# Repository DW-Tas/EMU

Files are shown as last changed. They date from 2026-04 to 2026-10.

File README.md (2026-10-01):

[][cc-by-nc-sa]

# EMU – Expandable Multi-material Unit
### A new take on a MMU by <a href="https://github.com/DW-Tas">DW-Tas</a> and <a href="https://github.com/igiannakas">igiannakas</a><br/>
<a href="https://ko-fi.com/O5O5OCC0K"> Ko-Fi</a>

**Introducing the EMU, the Expandable Multi-material Unit from down under.** The EMU is a modular, flexible, upgradable, reliable and service-friendly MMU designed around the proven filamentalist V3 platform.

The EMU supports any number of lanes and base configurations; whether it is a **single lane setup** to assist filament loading, a **dual lane configuration** for endless spool, or a **multi-lane, multi base unit setup** for multi-material printing. It is also **expandable**, with no re-printing of parts required when upgrading from a 2 lane to a multiple lane setup.

> [!TIP]
> ### EMU Kits
> Officially certified kits are now available. Further information on sourcing links, kits and kit classification can be found [in the dedicated sourcing page](https://github.com/DW-Tas/EMU/blob/main/docs/sourcing.md).
> ### Crossbow Filament Cutter And A4T Toolhead
> Make the EMU part of a complete system with the [Crossbow Filament Cutter](https://github.com/DW-Tas/Crossbow-Filament-Cutter) and the [A4T Toolhead](https://github.com/Armchair-Heavy-Industries/A4T).

<p align="center">
  
</p>

## Discord - primary support communities
Join our active communities on Discord using the links below. We are active on both the Armchair Engineering, Happy Hare and Voron discord servers.<br/>
Join me on Discord (https://discord.gg/hG2NRazKG3)   
<br>
**HappyHare Discord:** https://discord.gg/Yt8Fe7FkNc

## Table of Contents
- [Design Objectives](#design-objectives)
- [Documentation](/docs)
  - [Sourcing](/docs/sourcing.md)
  - [Printed parts configurator](https://emu.dwtas.net)
  - [Printing, Assembly and Wiring](/docs/assembly_wiring)
  - [Board Setup and Flashing](/docs/software_setup/01-board-setup.md)
  - [Software Setup](/docs/software_setup/02-software-setup.md)
  - [Calibration and Startup](/docs/software_setup/03-calibration-and-startup.md)
  - [Expanding the Unit](/docs/software_setup/04-expanding-the-unit.md)
  - [Slicer setup and optimisation for multi color prints](/docs/software_setup/05-slicer-setup.md)
  - [Updating CAN Boards with UKAM](/docs/software_setup/06-updating-can-boards.md)
  - [Manual Sensorless Toolhead Calibration for Happy Hare](/docs/software_setup/07-manual-toolhead-calibration.md)
  - [Manual Toolhead Calibration with Two Sensors for Happy Hare](/docs/software_setup/08-manual_toolhead_calibration_two_sensors.md)
  - [Legacy Happy Hare v3 guides (archive)](/docs/software_setup/legacy_hhv3)
- [Render Gallery](#render-gallery)
- [Prints Gallery](#prints-gallery)
- [License](#this-work-is-licensed-under-a)

## EMU Highlights
- **Modular & Expandable** design, able to add lanes anytime and in any configuration. No reprints when upgrading from a 2 lane setup.
- **One screw or tool-free** access and servicing, even mid-print.
- **Sealed dry boxes** able to maintain humidity in the 15% range (with silica gel) or 5–8% range (with molecular sieves) for weeks.  
- **Humidity sensors** per lane for filament environmental monitoring.
- **Reliable endless spool** with no chance of the rewound filament interfering with neighbouring rolls.
- **Off-the-shelf electronics** (EBB42 with EBB36 also fully compatible). Custom designed Solo Lane Boards (SLB) available as an option, to ease wiring.
- **Per-lane controls** - eject button + LEDs.

<p align="center">
  
  
</p>

## Design Objectives

### Modularity & Upgradeability  
Each lane is fully self-contained, so you can choose **exactly how many lanes you need and group them as you like**. You can also **mix and match** lanes across multiple base units, or use a stand-alone single lane for extruder loading and print assistance. 

Expanding later is also straightforward. Just print lane expanders for the base and add another dry box assembly. There is no need to reprint or replace existing parts when upgrading from a 2 lane base. 

### Ease of Servicing 
All electrical and mechanical components are either **one screw or completely tool-free and immediately accessible**, making live troubleshooting possible even during a print. 

Access to the electronics is easy - just lift the dry box off its base for full access. The stepper tensioning screw is accessible without any disassembly allowing on the fly tuning of filament grip. Finally, removing the filamentalist, stepper and stepper assembly is possible via one screw.

### Sealed Dry Boxes  
Each spool sits in its own purpose built, **fully sealed dry box with an integrated desiccant holder**. The boxes use foam cord in areas of potential air ingress to create a tight seal, with the clear 1.5mm PETG/PC panel also offering visibility inside the dry box.

The dry boxes can maintain humidity in the 15% range (with silica gel) or 5–8% range (with molecular sieves) for weeks. Finally, as each dry box is self contained, opening one to reload filament, doesn’t disturb its neighbours, extending the effective desiccant life.

<p align="center">
  
</p>

### Integrated Humidity Sensors 
Each lane monitors its own environment, letting you know when it’s **time to refresh the desiccant**. The humidity sensors are integrated into Mainsail (and optionally in Home Assistant for historical data tracking via the mainsail HA integration).

### Endless Spool Reliability
Dual pre-stepper sensors ensure **consistent run-out detection** and reliable re-wind, as the filament is always gripped by the stepper hobbed gear assembly. 

In addition, the isolated boxes ensure that any left over, rewound, filament cannot interfere with neighbouring lanes, **preventing a jam**.

### Built on the Filamentalist
The lane assembly is based on the proven **[filamentalist V3 design with 688 bearings](https://github.com/Enraged-Rabbit-Community/ERCF_v2/tree/master/Recommended_Options/Filamentalist_Rewinder/Filamentalist_FV3_Rewinder)** with wide spool size compatibility. Built on the 74mm filamentalist setup, the unit fits even the slightly wider KVP filament spools.

<p align="center">
  
  
</p>

### Integrated Filament Driving Stepper 
Each lane has its own driving stepper inside the dry box, resulting in a compact, **fully self-contained mechanical design**. In case of mechanical issue, you can swap out filamentalist assemblies with 3 screws, unplugging 2 JST plugs and unplugging the bowden tube. 

In addition, you can **swap out complete dry boxes** by unplugging two JST plugs and the bowden tube. This is helpful if you want to maintain a particularly moisture sensitive filament undisturbed when swapping it out from the EMU.

### Simple Electronics
The recommended BOM uses the custom designed [Solo Lane Boards](https://www.aliexpress.com/item/1005012025112049.html) which simplify wiring greatly. Also the **readily available EBB42 & EBB36 boards** are fully compatible. MMB v2 boards (or any other controller board with adequate number of endstops) can also be reused, though without humidity sensing due to I²C limitations and a slightly more intricate wiring. 

In addition, **each lane has its own ventilation fan**, ensuring the stepper drivers do not overheat, even when the unit is placed on top of a hot printer.

### Easy mounting
The EMU base assembly can be securely **mounted on extrusions** or using **rubber feet** directly on the printer or besides it. In either case the **electronics remain accessible** without needing to remove the unit from its mounts.

### Per-lane Controls  
Each lane includes its own eject button, status LED, and a filament colour LED that illuminates the dry box. 

## Render Gallery
<p align="center">
  
  
</p>
<p align="center">
  
  
</p>
<br/>

## Prints Gallery
<p align="center">
  1 (4)
  1 (5)
  1 (2)
  1 (3)
</p>

## Mods to main
The following mods from the community have been adopted into the main EMU release
 - Rim roller with square nuts: [martijnvanduijneveldt](https://github.com/martijnvanduijneveldt)
 - EMU Wiring Hatch Board: [kashine6](https://github.com/kashine6)

## This work is licensed under a
[Creative Commons Attribution-NonCommercial-ShareAlike 4.0 International License][cc-by-nc-sa].

[][cc-by-nc-sa]

[cc-by-nc-sa]: http://creativecommons.org/licenses/by-nc-sa/4.0/
[cc-by-nc-sa-image]: https://licensebuttons.net/l/by-nc-sa/4.0/88x31.png
[cc-by-nc-sa-shield]: https://img.shields.io/badge/License-CC%20BY--NC--SA%204.0-lightgrey.svg

## License clarification regarding non-commercial use:
The non-commercial aspect of this license is for cases where EMU is the product, not the use of EMU to create products.<br/>
I.e. If you wish to sell EMU as a product, you would need to seek a commercial license before doing so. </br>
It is NOT intended to prevent the use of EMU with a printer that you use to provide commercial services. If you want to run EMU in your print farm, go right ahead.

---

[Documentation →](/docs)

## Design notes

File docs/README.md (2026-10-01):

[][cc-by-nc-sa]

# EMU – Expandable Multi-material Unit Documentation
### A new take on a MMU by <a href="https://github.com/DW-Tas">DW-Tas</a> and <a href="https://github.com/igiannakas">igiannakas</a><br/>
<a href="https://ko-fi.com/O5O5OCC0K"> Ko-Fi</a>

<p align="center">
  
</p>

## Step 1: [Sourcing](/docs/sourcing.md)
The dedicated [sourcing page](/docs/sourcing.md) contains kit, certification and BOM information.

## Step 2: [Printing, Assembly and Wiring](/docs/assembly_wiring)
This page explains the EMU parts printing, assembly and wiring. It contains the [printed parts configurator, which allows you to select the desired number of lanes and build options](https://emu.dwtas.net), detailed print settings for all of the EMU parts, including tips on how to achieve the optimal print results. It also includes the [assembly manuals](/Manuals), (legacy) videos and covers multi-lane and single-lane wiring for EMU SLB, EBB42 & 36 boards.

- [Printed parts configurator](https://emu.dwtas.net)
- [Print Settings](/docs/assembly_wiring/#print-settings)
  - [Filamentalist components and Lane stepper components](/docs/assembly_wiring/#filamentalist-components-and-lane-stepper-components)
  - [Dry Box components](/docs/assembly_wiring/#dry-box-components)
  - [Base unit components](/docs/assembly_wiring/#base-unit-components)
- [Assembly Manuals](/docs/assembly_wiring/#assembly-manuals)
- [Assembly Videos](/docs/assembly_wiring/#assembly-videos)
  - [Part 1: Filamentalist and Stepper Assembly Guide](/docs/assembly_wiring/#part-1-filamentalist-and-stepper-assembly-guide)
  - [Part 2: Drybox Assembly Guide](/docs/assembly_wiring/#part-2-drybox-assembly-guide)
  - [Part 3: Base Assembly Guide](/docs/assembly_wiring/#part-3-base-assembly-guide)
  - [Part 4: Electronics Assembly Guide](/docs/assembly_wiring/#part-4-electronics-assembly-guide)
- [Wiring Instructions and Diagrams](/docs/assembly_wiring/#wiring-instructions-and-diagrams)

## Step 3: [EMU Board Setup](/docs/software_setup/01-board-setup.md)
This page explains in detail how to setup your EMU boards with CANBus, how to flash Katapult and klipper as well as the procedure to update the klipper firmware.

- [Setting up CAN Bus](/docs/software_setup/01-board-setup.md#setting-up-can-bus)
- [Setting up and flashing the EBB boards](/docs/software_setup/01-board-setup.md#setting-up-and-flashing-the-ebb-boards)
- [Updating the boards with the latest klipper version](/docs/software_setup/01-board-setup.md#updating-the-boards-with-the-latest-klipper-version)

## Step 4: [Software Setup](/docs/software_setup/02-software-setup.md)
The EMU needs MMU control software running alongside Klipper. Both of the options below support the EMU natively. The EMU was developed on Happy Hare and it's the software we have the most experience with. However, AFC is equally an option if you prefer it or already use it, with its setup covered in the AFC documentation.

**Happy Hare v4:** The step by step install and set up process is maintained in the Happy Hare documentation. EMU-specific notes are on the [companion page in this repo](/docs/software_setup/02-software-setup.md#happy-hare-v4).

- [Getting Started with EMU (Happy Hare v4 documentation)](https://moggieuk.github.io/Happy-Hare-Doc/GettingStarted-EMU/)
- [EMU notes for the v4 installer](/docs/software_setup/02-software-setup.md#emu-notes-for-the-v4-installer)
- [Legacy Happy Hare v3 setup guide](/docs/software_setup/legacy_hhv3/02-happy-hare-setup.md) (existing v3 installs only)

**AFC (AFC-Klipper-Add-On):** In the AFC installer (`install-afc.sh`), choose **EMU** as the unit type, then set your lane count and board type (SLB or EBB). Follow the [AFC documentation](https://www.afcproject.dev/) for the full process.

- [AFC installation guide](https://www.afcproject.dev/installation/getting-started.html)
- [AFC Initial Startup & Commissioning guide](https://www.afcproject.dev/initial-startup/01-overview.html) (select the EMU tab)

> [!NOTE]
> Step 5 (Calibration and Startup), the machine G-code in Step 6 (Slicer Setup) and [Expanding the unit](/docs/software_setup/04-expanding-the-unit.md) are written for Happy Hare. If you use AFC, follow the AFC [calibration](https://www.afcproject.dev/installation/calibration.html) and [slicer setup](https://www.afcproject.dev/installation/slicer-setup.html) guides instead.

## Step 5: [Calibration and Startup](/docs/software_setup/03-calibration-and-startup.md)
This page explains the initial start up checks required to ensure successful first operation, and the step by step process to calibrate the unit.

- [First start up](/docs/software_setup/03-calibration-and-startup.md#first-start-up)
- [Calibrating the unit](/docs/software_setup/03-calibration-and-startup.md#calibrating-the-unit)
- [Manual unit calibration (optional)](/docs/software_setup/03-calibration-and-startup.md#manual-unit-calibration-optional---if-not-satisfied-with-automated-calibrations)

## Step 6: [Slicer Setup and Optimisation for Multi Color Prints](/docs/software_setup/05-slicer-setup.md)
Describes the mandatory Orca slicer setup required for single extruder multi-material printing, including print profile settings to achieve optimal quality results.

- [Orca slicer mandatory setup](/docs/software_setup/05-slicer-setup.md#orca-slicer-mandatory-setup)
- [Orca slicer profile tuning for multi-color printing](/docs/software_setup/05-slicer-setup.md#orca-slicer-profile-tuning-for-multi-color-printing)

## Step 7: [Updating CAN Boards with UKAM](/docs/software_setup/06-updating-can-boards.md)
Automate Klipper firmware updates across all your EMU CAN bus boards using UKAM (Update Klipper And MCUs), instead of manually flashing each board.

## Next steps
Once you have completed the steps above you should have a fully functioning EMU unit! Optionally you can also set up:
1. Klipper screen integration: https://moggieuk.github.io/Happy-Hare-Doc/KlipperScreen/
2. Mainsail / Fluidd MMU panel: https://moggieuk.github.io/Happy-Hare-Doc/Mainsail-Fluidd-Integration/
3. Spoolman: https://moggieuk.github.io/Happy-Hare-Doc/Feature-Spoolman/

In addition, to add further lanes, follow the instructions here: [Expanding the unit](/docs/software_setup/04-expanding-the-unit.md)

> [!NOTE]
> **Running Happy Hare v3?** The previous v3 setup, calibration and expansion guides are kept in the [legacy Happy Hare v3 archive](/docs/software_setup/legacy_hhv3).

## Seeking help

Join our active communities on Discord using the links below. We are active on both the Armchair Engineering and Happy Hare discord servers below.

Join me on Discord (https://discord.gg/hG2NRazKG3)   
<br>
**HappyHare Discord:** https://discord.gg/Yt8Fe7FkNc

#### This work is licensed under a
[Creative Commons Attribution-NonCommercial-ShareAlike 4.0 International License][cc-by-nc-sa].

[][cc-by-nc-sa]

[cc-by-nc-sa]: http://creativecommons.org/licenses/by-nc-sa/4.0/
[cc-by-nc-sa-image]: https://licensebuttons.net/l/by-nc-sa/4.0/88x31.png
[cc-by-nc-sa-shield]: https://img.shields.io/badge/License-CC%20BY--NC--SA%204.0-lightgrey.svg

### License clarification regarding non-commercial use:
The non-commercial aspect of this license is for cases where EMU is the product, not the use of EMU to create products.<br/>
I.e. If you wish to sell EMU as a product, you would need to seek a commercial license before doing so. </br>
It is NOT intended to prevent the use of EMU with a printer that you use to provide commercial services. If you want to run EMU in your print farm, go right ahead.

---

← [Main README](/) | [Step 1: Sourcing →](/docs/sourcing.md)

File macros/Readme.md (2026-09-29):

# EMU – Custom macros and Klipper modules

This folder contains three sets of files:
1. `emu_macros.cfg`
2. Klipper module patches for the AHT and BME sensors
3. UKAM menuconfig templates to automate Klipper firmware updates

## Using the emu_macros.cfg file
Place the `emu_macros.cfg` file in your printer configuration folder. Update your `printer.cfg` to use it by adding the following line after all the MMU macro inclusions:

`[include emu_macros.cfg]`

Configure the macros [as per the instructions in the legacy Happy Hare v3 setup guide](https://github.com/DW-Tas/EMU/blob/main/docs/software_setup/legacy_hhv3/02-happy-hare-setup.md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).

Both HW and SW I2C bus definitions are included. If planning to use the upcomming EMU NFC reader functionality, HW I2C is required. Please note in some setups HW I2C may generate NACK errors. If you do encounter that, check wiring crimping and at worst revert to SW I2C (but without NFC functionality).

## Using the custom Klipper modules
The stock Klipper setup has two shortcomings when using a BME or AHT sensor:
1. The BME sensor polls every 0.8 seconds, placing needless load on the MCU.
2. The AHT sensor does not report humidity to 1 decimal place; instead, it rounds to a whole number.

The two included files are drop-in replacements for Klipper modules and address these two shortcomings. Specifically for the BME sensor, the default polling behaviour is set to 5 seconds and is also configurable from your `emu_macros.cfg` file as shown below:

```
[temperature_sensor Lane_0]
sensor_type: BME280
bme280_report_time: 120 # new parameter controlling polling frequency
i2c_address: 118
i2c_mcu: mmu0
i2c_software_scl_pin: mmu0:PB3
i2c_software_sda_pin: mmu0:PB4
```
To use these files, download them from the EMU repo and upload them to your SBC in the following location, overwriting the default files: `~/klipper/klippy/extras`

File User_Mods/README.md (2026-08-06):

# EMU User Mods

Community-contributed modifications and additions for the EMU (Expandable Multi-material Unit). Browse the table below to find mods that extend or customise your EMU setup.

## Usermods

| Mod | Author | Description | Preview |
|-----|---|---|---|
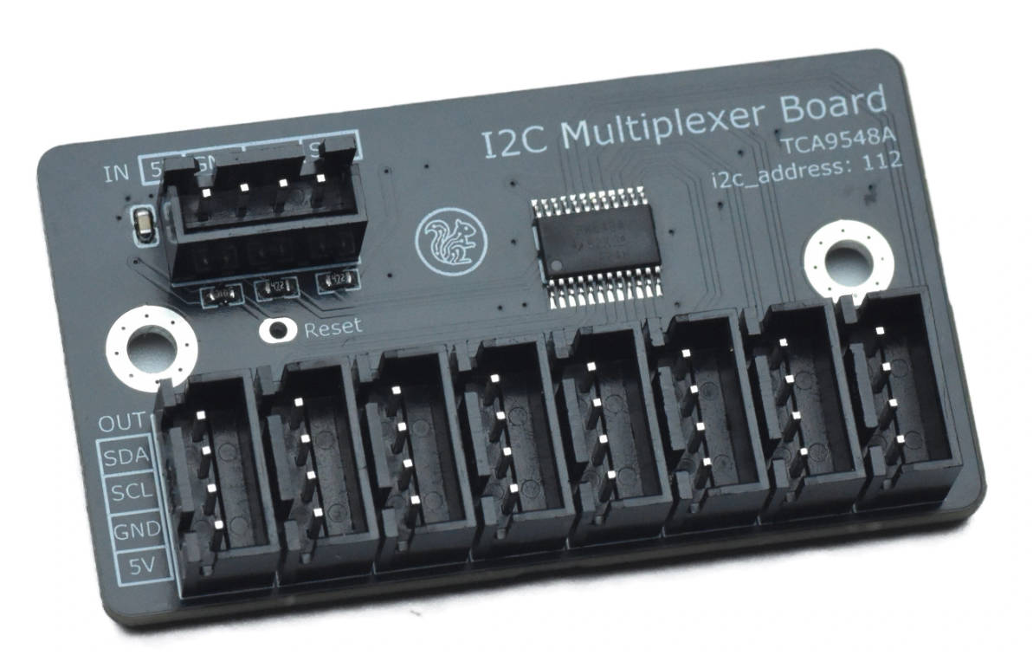
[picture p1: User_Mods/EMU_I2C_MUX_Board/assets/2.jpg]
| [EMU_I2C_MUX_Board](EMU_I2C_MUX_Board) | [kashine6](https://github.com/kashine6) | Custom TCA9548A I2C Mux Board for MMB Users |  |
| [DFRobot SHT31 Holder](DFRobot_SHT31_Holder) | [reapola](https://github.com/reapola) | High-accuracy temperature & humidity sensor holder, replacing the standard BME280 |  |
| [EMU Cable Entry – Crimpable JST](EMU%20Cable%20Entry_Crimpable_JST) | [Dragi2k](https://github.com/Dragi2k) | Cable entry module with crimpable JST socket options for 3- and 4-pin configurations |  |
| [EMUSync Mount](EMUSync_Mount) | [cwiegert](https://github.com/cwiegert) | Mount to stabilise the PSF body in the bowden path with perpendicular or parallel mounting options |  |
| [EMU Cable Entry Blank Plate](EMU_Cable_Entry) | [bartlammers](https://github.com/bartlammers) | Blank cable entry plate for sides without cables, compatible with multimaterial printing |  |
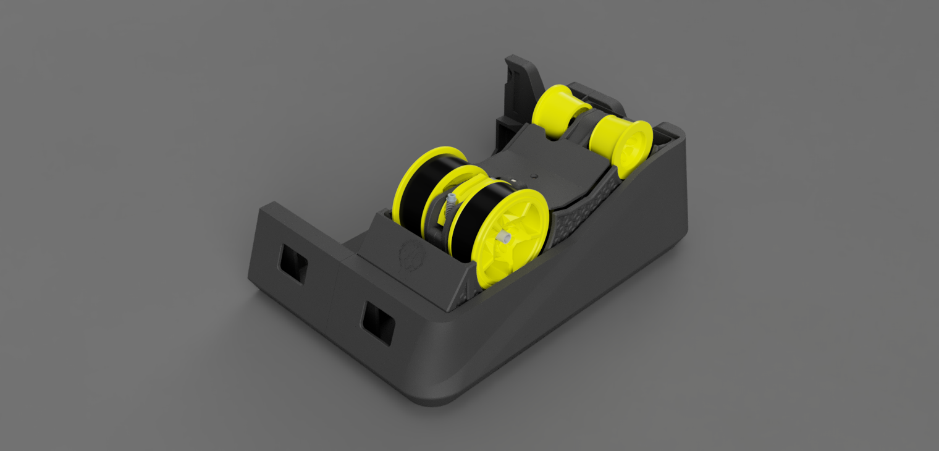
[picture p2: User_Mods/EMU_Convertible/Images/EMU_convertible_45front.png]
| [EMU Convertible](EMU_Convertible) | [Dragi2k](https://github.com/Dragi2k) | Use wider spools (84 mm) in outer bays or centre with the adjacent bay populated |  |
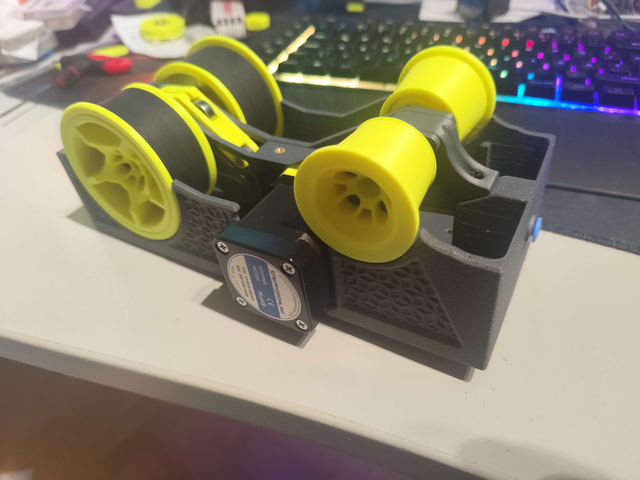
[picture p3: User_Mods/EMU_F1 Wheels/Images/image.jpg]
| [EMU F1 Wheels](EMU_F1%20Wheels) | [Dragi2k](https://github.com/Dragi2k) | Stylish wheel remix compatible with EMU Lite and EMU Convertible for wider wheel accommodation |  |
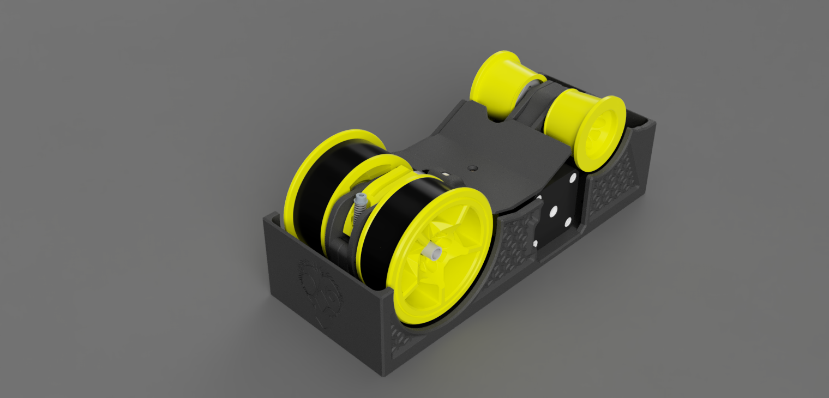
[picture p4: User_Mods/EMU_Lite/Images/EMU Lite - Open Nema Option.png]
| [EMU Lite](EMU_Lite) | [Dragi2k](https://github.com/Dragi2k) | Simplified EMU without lid or base, fully compatible with EMU Filamentalist and hatch board |  |
| [EMU Roller Rubber Installer](EMU_Roller_Rubber_Installer) | [wil1972](https://github.com/wil1972) | Tools for cutting and installing rubber bike tyre on EMU rollers using zip ties |  |
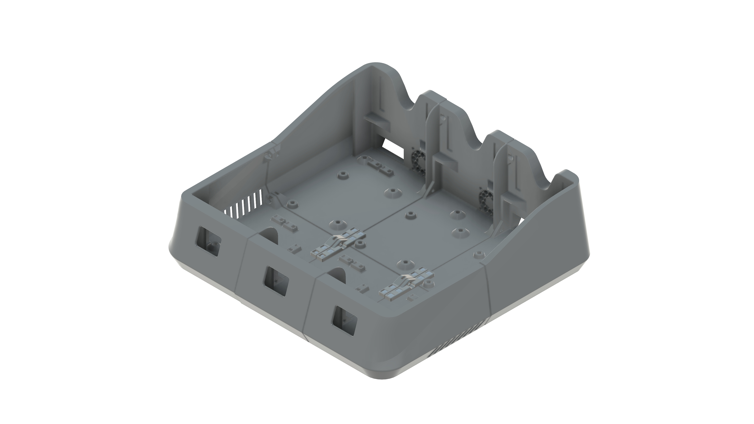
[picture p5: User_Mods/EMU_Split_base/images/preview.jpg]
| [EMU Split base](EMU_Split_base) | [martijnvanduijneveldt](https://github.com/martijnvanduijneveldt) | Split base version for smaller printers |  |
| [Micron EMU Hat](MicronEMU) | [burkfers](https://github.com/burkfers) | Base unit mod fitting three EMU boxes onto a Micron with a stealth aesthetic |  |
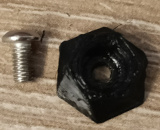
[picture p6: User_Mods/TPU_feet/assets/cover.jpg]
| [printable TPU feet](TPU_feet) | [burkfers](https://github.com/burkfers) | Small M3-mounted printable feet for the bottom of the base |  |
| [Rim Roller with Square Nuts](Rim_Roller_with_square_nuts) | [martijnvanduijneveldt](https://github.com/martijnvanduijneveldt) | Rim roller remix using square nuts instead of screwing directly into plastic |  |
| [Trianglelab BLV kit mods](Trianglelab_BLV%20kit%20mods) | [DW-Tas](https://github.com/DW-Tas) | PTC212-413 connector holder as a Wago 221 alternative for the Trianglelab BLV kit | — |

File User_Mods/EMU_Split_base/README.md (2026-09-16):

# EMU Split base

| Top view | Bottom view |
|---|---|
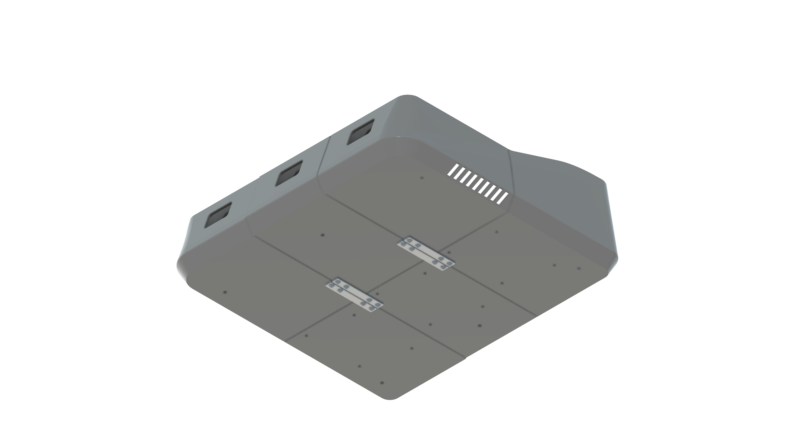
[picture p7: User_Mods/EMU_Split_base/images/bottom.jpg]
| Preview |  |

A remix splitting the different base parts so they can be printed on smaller printers.

The position of the side connector matches of original position, so mixing split bases with full bases it possible.

> This mod adds some protrusion (~4mm) on the bottom, so feet are required (even if they are already part of the standard bom).

## Extra required bom

The M3x8 SHCS screw + square nut to interconnect the lanes is already in the base bom so it's not needed as 'extra' for each lane.

### Left and right lane
These are the extra requirements for a single side, multiply by 2 if printing both sides

|Amount | Part | Placement |
|---|---|---|
| 2x | M3x8 SHCS | On the outer side of the box | 
| 4x | M3x8 BHCS | On the bottom of the inner side connector |
| 4x | Square nuts | On the top of the inner side connector |

### Expander lane(s)

|Amount | Part | Placement |
|---|---|---|
| 8x | M3x8 BHCS | On the bottom of the side connectors |
| 8x | Square nuts | On the top of the side connectors |

## Credits
- Original mod by [martijnvanduijneveldt](https://github.com/martijnvanduijneveldt)
- Printed & tested by [DeWarePeb](https://github.com/DeWarePeb)

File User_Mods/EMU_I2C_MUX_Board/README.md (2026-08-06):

# EMU I2C MUX Board

This user mod is a small PCB for wiring a TCA9548A I2C multiplexer into an
EMU setup more cleanly.

## Why

Some users may want to repurpose spare MMU controller boards, such as the MMB
or AFC-Lite, to build an EMU. In these configurations, convenient I2C connection 
points can run short when multiple I2C devices are connected. A TCA9548A multiplexer 
allows several downstreamI2C devices to share a single upstream I2C bus while keeping 
the devices isolated on separate mux channels.

This board was made to make that wiring easier and cleaner.

**Note:**

> Compared with the common off-the-shelf TCA9548A breakout board, this PCB does
> not add any new electrical or software functionality. Its purpose is only to
> simplify and organize the wiring for an EMU installation.

<p align="center">
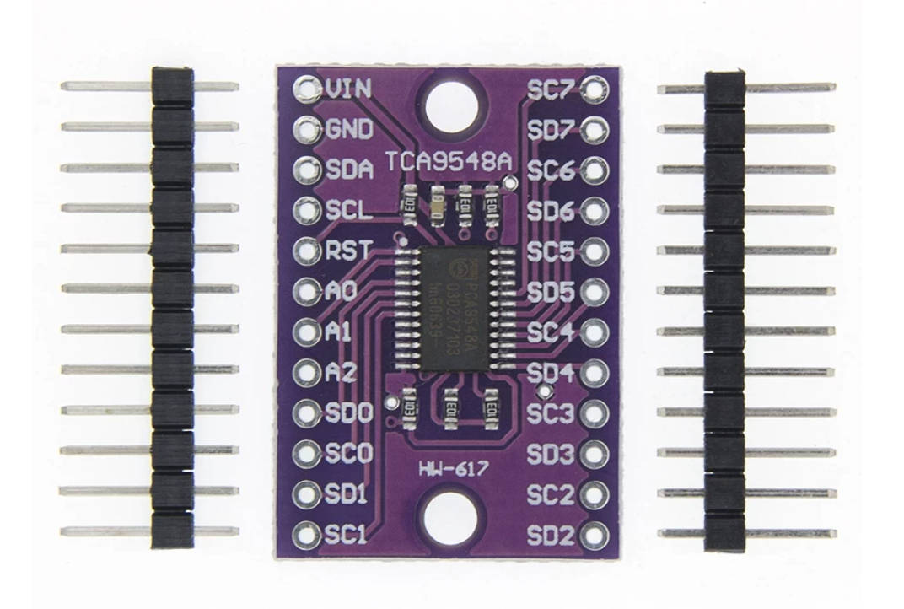
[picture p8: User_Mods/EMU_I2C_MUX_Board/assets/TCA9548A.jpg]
TCA9548A HW-617 breakout board
  
</p>

## Hardware

**Gerber** files for the PCB are included in this project, allowing you to order the board from 
your preferred PCB manufacturer.

Alternatively, you can purchase a PCB from AliExpress. Ordering it together with other EMU 
parts can help reduce shipping costs.

- https://www.aliexpress.com/item/1005011529532141.html

<p align="center">
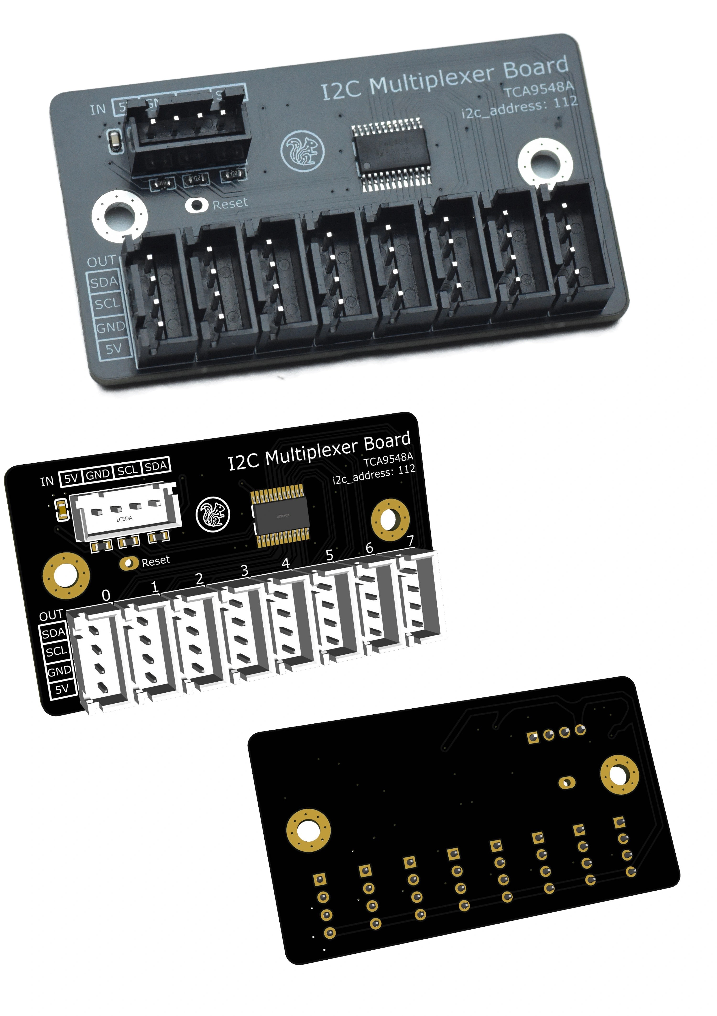
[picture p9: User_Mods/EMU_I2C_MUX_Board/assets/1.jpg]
EMU I2C MUX Board
  
</p>

## Mount
The PCB mount designed for EMU Lane Base is also available in this repository.

## Software

The matching Klipper software add-on is maintained separately:

<https://github.com/jacksky6/TCA9548A-klipper-addon>

That software project provides the actual TCA9548A mux support for Klipper,
including serialized channel selection and sensor adapters for devices behind
the mux. This PCB is only a wiring convenience board. It does not replace the
software add-on.

## License

This user mod is licensed under the Creative Commons
Attribution-NonCommercial-ShareAlike 4.0 International license.

See: <https://creativecommons.org/licenses/by-nc-sa/4.0/>

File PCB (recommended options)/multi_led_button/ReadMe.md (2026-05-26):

## EMU LED PCB

The **EMU LED PCB** is a dedicated PCB designed for the EMU to enable dynamic lighting effects on the eject button assembly. It also simplifies wiring and reduces the need for soldering.

LED PCB

## BOM variations vs. baseline EMU BOM
Do not purchase the below from the base BOM:
1. 1 less neopixel
2. 1 less D2F-L switch
3. 4 less 6x3mm magnets

Add the below to the base BOM, depending on your LED PCB source:
1. 1x JST-XH 5 pin PCB header

## Manual
Assembly and wiring instructions are outlined [in the manual](/Manuals/EMU_LED_Button_PCB.pdf).

## Sourcing
The LED button PCBs can be sourced from the below location:
1. [Aliexpress](https://www.aliexpress.com/item/1005011529532141.html) in sets of 5

Alternatively use the supplied gerber, BOM and pick and place files to order from your favourite PCB manufacturer.

## Software setup

Update your **LED definitions** in the mmu_hardware.cfg as below. **Key change is chain count is equal to 5 instead of 2.**
```
[neopixel mmu0_leds] # one block per lane (Lane 0)
pin: mmu0:MMU_NEOPIXEL
chain_count: 5			# four for the eject button and one for the box
color_order: GRBW		

[neopixel mmu1_leds] # one block per lane (Lane 1)
pin: mmu1:MMU_NEOPIXEL
chain_count: 5			# four for the eject button and one for the box
color_order: GRBW	

[....]

[neopixel mmuN_leds] # one block per lane (Lane 1)
pin: mmuN:MMU_NEOPIXEL
chain_count: 5			# four for the eject button and one for the box
color_order: GRBW
```
Update your **LED allocation** to exit and entry LEDs in the mmu_hardware.cfg as below. **Key change is that leds 1 through to 4 are exit LEDs and LED 5 is the entry LED.**
```
[mmu_leds unit0]
exit_leds:
  neopixel:mmu0_leds (1,2,3,4) # add/remove lines to match number of lanes. LED 1-4 is for the button
  neopixel:mmu1_leds (1,2,3,4)
  [...]
  neopixel:mmuN_leds (1,2,3,4)
entry_leds:
  neopixel:mmu0_leds (5) # add/remove lines to match number of lanes. LED 5 is for the box
  neopixel:mmu1_leds (5)
  [...]
  neopixel:mmuN_leds (5)
frame_rate: 24
```
Update the **mmu eject button hardware configuration** in the **mmu_eject_buttons_hw.cfg file**<br/><br/>
The below example setup is for an 8 lane unit. To set up a lower lane count, delete the corresponding `[gcode_button mmu_eject_button_N]` sections. If you have more than 8 lanes, add more blocks following the pattern below. 

Please note the `!` which is different to the software setup that uses D2F switches!

```
[gcode_button mmu_eject_button_0]
pin: ^!mmu0:EJECT_BUTTON
press_gcode: _MMU_EJECT_BUTTON GATE=0

[gcode_button mmu_eject_button_1]
pin: ^!mmu1:EJECT_BUTTON
press_gcode: _MMU_EJECT_BUTTON GATE=1

[gcode_button mmu_eject_button_2]
pin: ^!mmu2:EJECT_BUTTON
press_gcode: _MMU_EJECT_BUTTON GATE=2

[gcode_button mmu_eject_button_3]
pin: ^!mmu3:EJECT_BUTTON
press_gcode: _MMU_EJECT_BUTTON GATE=3

[gcode_button mmu_eject_button_4]
pin: ^!mmu4:EJECT_BUTTON
press_gcode: _MMU_EJECT_BUTTON GATE=4

[gcode_button mmu_eject_button_5]
pin: ^!mmu5:EJECT_BUTTON
press_gcode: _MMU_EJECT_BUTTON GATE=5

[gcode_button mmu_eject_button_6]
pin: ^!mmu6:EJECT_BUTTON
press_gcode: _MMU_EJECT_BUTTON GATE=6

[gcode_button mmu_eject_button_7]
pin: ^!mmu7:EJECT_BUTTON
press_gcode: _MMU_EJECT_BUTTON GATE=7
```

## Wiring variations
The DOut pin (LED out) should connect to a 600mm AWG26-28 wire going to the LED IN pin of the lane dry box. That way the third wago can be omitted.

## Lighting effects
The multiple LEDs incorporated in the eject button allow you to create loading/unloading animations like the below. Also the integrated SMD switch provides a more tactile feel vs. the D2F switch and magnet assembly. 

The lighting effects are enabled automatically by happy hare.

https://github.com/user-attachments/assets/2f268710-e0a5-41e1-b007-02235ff379cc

## This work is licensed under a
[Creative Commons Attribution-NonCommercial-ShareAlike 4.0 International License][cc-by-nc-sa].

[][cc-by-nc-sa]

[cc-by-nc-sa]: http://creativecommons.org/licenses/by-nc-sa/4.0/
[cc-by-nc-sa-image]: https://licensebuttons.net/l/by-nc-sa/4.0/88x31.png
[cc-by-nc-sa-shield]: https://img.shields.io/badge/License-CC%20BY--NC--SA%204.0-lightgrey.svg

## License clarification regarding non-commercial use:
The non-commercial aspect of this license is for cases where EMU is the product, not the use of EMU to create products.<br/>
I.e. If you wish to sell EMU as a product, you would need to seek a commercial license before doing so. </br>
It is NOT intended to prevent the use of EMU with a printer that you use to provide commercial services. If you want to run EMU in your print farm, go right ahead.

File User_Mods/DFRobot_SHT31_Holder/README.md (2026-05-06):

# DFRobot SHT31 Temperature & Humidity Sensor Holder

Hot & Sweaty

## Overview
High(er) accuracy temperature & humidity sensor for use in the boxes instead of a BME280.

- Pros
    - ±2%RH at 0%RH to 100%RH (at 25°C）humidity accuracy Vs. ±3%RH 20%RH to 80%RH
    - -40°C to 125°C temperature detection range Vs. -40°C to 85°C range (although if its that hot, you've got bigger problems!)
    - Legit Fermion sensor Vs. potential BME280 clones

- Cons
    - Bigger footprint
    - More expensive (~£7 Vs. £4 per sensor)

## BOM
- DFRobot part no: SEN0331

## Where to get them?

Stick to suppliers with a known supply chain.

#### Worldwide
- [Mouser](https://www.mouser.co.uk/c/?q=SEN0331)
- [Digikey](https://www.digikey.co.uk/en/products/detail/dfrobot/SEN0331/12324931)

#### UK
- [ThePiHut](https://thepihut.com/products/fermion-sht31-digital-temperature-humidity-sensor?variant=42046092607683)
- [Farnell](https://uk.farnell.com/dfrobot/sen0331/temp-humidity-sensor-breakout/dp/4308263)

## Print settings
Standard EMU settings (999 walls) with shrinkage factor for your chosen filament.

Hot & Sweaty

## Code

By default the SHT3X klipper module expects the sensor on 68 (0x44), however the DFRobot sensors can be found at 69 (0x45) unless ADR is connected to connected to GND.  Report time is set to poll every 120secs to reduce load on the mcus.

#### Example config for Lane_0 found in emu_macros.cfg

    [temperature_sensor Lane_0]
    sensor_type: SHT3X
    i2c_address: 69
    i2c_mcu: mmu0
    i2c_software_scl_pin: mmu0:PB3
    i2c_software_sda_pin: mmu0:PB4
    sht3x_report_time: 120

#### How it should look when working (4 lane example)

Working example

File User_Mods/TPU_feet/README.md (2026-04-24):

# Printable feet

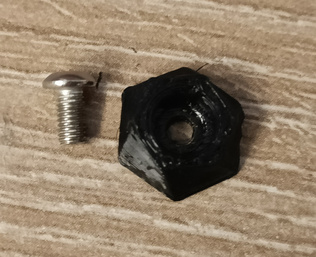
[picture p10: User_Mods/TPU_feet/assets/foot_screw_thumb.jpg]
a photograph of the foot in TPU next to an M3x6 BHCS on a wooden desk


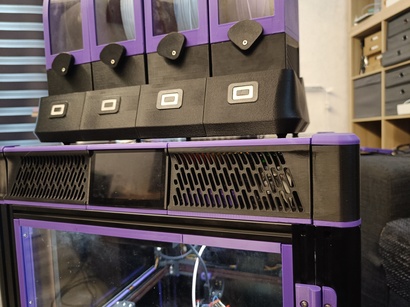
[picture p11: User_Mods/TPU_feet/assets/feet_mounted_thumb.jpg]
a photograph of a 4 lane EMU on top of a Doomcube, angled to show the gap and the feet


This small print adds reasonably low profile feet to the EMU. They can be printed in a flexible material to absorb some vibrations (especially when placed on top of the printer) and provide grip.

They have been tested in 95A TPU, printed with one wall, three tops and bottoms, and 10% gyroid infill.

Mount with an M3x6 BHCS each. Do not overtorque flexibles!

## Acknowledgements

Thanks to hartk for the inspiration by way of his Micron hexagonal feet.

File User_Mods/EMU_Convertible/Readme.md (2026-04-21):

# EMU Convertible

This mod allows the use of wider spools. In the outer bays of the base or in the center with an adjacent bay populated, 84 mm spools can be used. Even wider spools can be used in the center without side bays.
<br><br>
It is fully compatible, so only the EMU filamentalist needs to be replaced to eliminate the need for calibration.

| Front 45° | Closed Front | Opened Front |
|---|---|---|
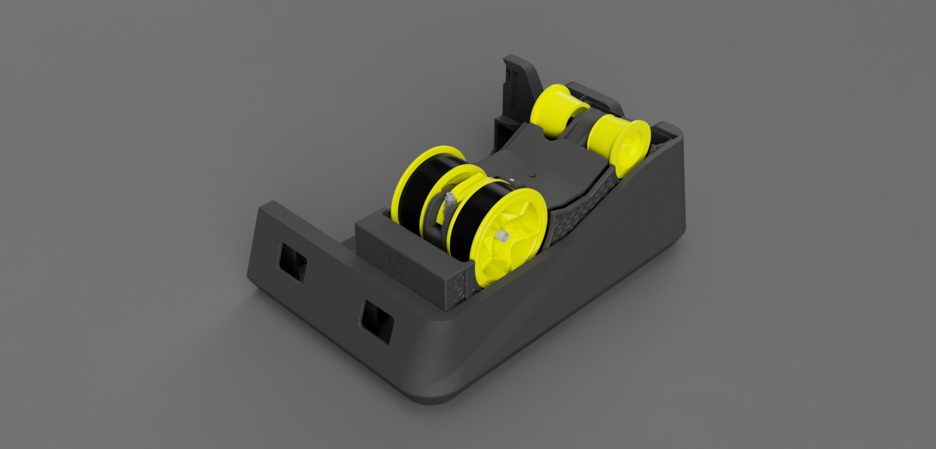
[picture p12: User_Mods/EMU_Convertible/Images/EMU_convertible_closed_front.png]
EMU Convertible closed front
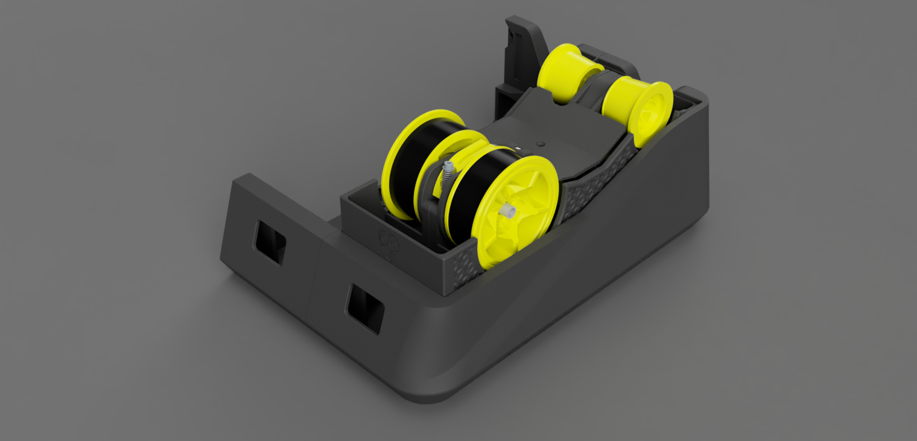
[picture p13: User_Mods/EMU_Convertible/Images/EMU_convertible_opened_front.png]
EMU Convertible opened front
| EMU Convertible 45 front |  |  |

by Dragi2k

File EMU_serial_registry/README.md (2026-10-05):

# EMU – Expandable Multi-material Unit - Official Serial Registry

EMU Serial Print by igiannakas

**Serial #0000:** dw.tas</br>
**Serial #0001:** igiannakas</br>
**Serial #0002:** Martijn</br>
**Serial #0003:** burkfers</br>
**Serial #0004:** WilLawUK</br>
**Serial #0005:** jacksky6</br>
**Serial #0006:** Heiliger-Gral</br>
**Serial #0007:** drachenkaetzchen</br>
**Serial #0008:** fronti</br>
**Serial #0009:** pajtaz</br>
**Serial #0010:** WoodWorker</br>
**Serial #0011:** Dragi2k</br>
**Serial #0012:** TheMeanCanEHdian</br>
**Serial #0013:** Bender</br>
**Serial #0014:** Pie36</br>
**Serial #0015:** ammaze</br>
**Serial #0016:** Doak</br>
**Serial #0017:** apoth82</br>
**Serial #0018:** .cicatrix</br>
**Serial #0019:** zoro__17</br>
**Serial #0020:** jimmyjon711</br>
**Serial #0021:** etherwalker</br>
**Serial #0022:** _yomgui_</br>
**Serial #0023:** sauyri</br>
**Serial #0024:** reapola</br>
**Serial #0025:** realadamator</br>
**Serial #0026:** ningpj</br>
**Serial #0027:** supercrossed</br>
**Serial #0028:** moadmoosa</br>
**Serial #0029:** niju5975</br>
**Serial #0030:** jb3duk</br>
**Serial #0031:** badman996</br>
**Serial #0032:** der_pw</br>
**Serial #0033:** hamido.</br>
**Serial #0034:** yssaril</br>
**Serial #0035:** _zimbo_</br>
**Serial #0036:** madscientist_304</br>
**Serial #0037:** mrga73</br>
**Serial #0038:** searsay3208</br>
**Serial #0039:** 8992</br>
**Serial #0040:** mrzottel79</br>
**Serial #0041:** bitmirth30</br>
**Serial #0042:** mahe_fi</br>
**Serial #0043:** etmolf</br>
**Serial #0044:** youngsterjon</br>
**Serial #0045:** margaale</br>
**Serial #0046:** bne6708</br>
**Serial #0047:** hcwarrior13</br>
</br>

### How to register:
Submit your build at [dwtas.net/EMUSerial](https://dwtas.net/EMUSerial). Sign in with Discord, upload a photo of your completed EMU Maker chip and unit, and a maintainer will review your submission.

Print [at least a two color version of the EMU Maker chip](https://github.com/DW-Tas/EMU/tree/main/EMU_serial_registry/serial_print_file). If your EMU lane can reach 4+ colors, try to use them all!

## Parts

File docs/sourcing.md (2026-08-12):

# EMU – Expandable Multi-material Unit Sourcing Options

## Sourcing Options
As EMU is using off the shelf hardware, you have 
two options to source the required components to build your unit: self sourcing and kits.

### EMU Kits
We require any officially authorised kits to **undergo a certification process**. During this process we test:
1. Completeness of the BOM
2. Fit of the mechanical parts
3. Level of effort required to complete the build
4. Convenience features for the user
5. Overall kit refinement

The kits are then classified into tiers, **Platinum**, **Gold**, **Silver**, **Bronze** as per the table below. 

This reflects the level of maturity of the kits and the overall user experience you should expect when ordering one.

It also allows us to offer feedback to the vendors to ensure the kits can result in a reliable unit and that any trade-offs are known up front to avoid buyer disappointment. 

### Certified Vendors List
<table style="width: 100%;">
  <tr>
    <th style="width: 10%;">Vendor</th>
    <th style="width: 30%;">Purchase Link</th>
    <th style="width: 30%;">Classification Tier</th>
    <th style="width: 30%;">Kit Summary</th>
  </tr>
  <tr>
    <td><strong>Vano3dla Maker Store</strong></td>
    <td><a href="https://www.aliexpress.com/item/1005012001238187.html">2 lane and 5 lane kit</a></td>
    <td>
      Platinum
    </td>
    <td>
      Platinum tier kit with all optional PCB options and exclusive PCB options included. High quality components, with exceptional fit and finish. Active support by the vendor in the Discord communities. <br><br> Initial batch of kits had the DIn - DOut silk screen on the Neopixel LEDs swapped around. 
    </td>
  </tr>
  <tr>
  <td><strong>DREMC (Vano3dla reseller)</strong></td>
  <td><a href="https://store.dremc.com.au/products/emu-the-expandable-multi-material-unit-hardware-kit">2 lane and 5 lane kit</a><br>Local Australian Stockist</td>
  <td>
    Platinum
  </td>
  <td>
    Platinum tier kit with all optional PCB options and exclusive PCB options included. High quality components, with exceptional fit and finish. Active support by the vendor in the Discord communities. <br><br> Initial batch of kits had the DIn - DOut silk screen on the Neopixel LEDs swapped around. 
  </td>
  </tr>
  <tr>
    <td><strong>onetwo3D</strong></td>
    <td><a href="https://www.onetwo3d.co.uk/product/emu-expandable-multi-material-unit-kit/">EMU base kit + lane kit(s)</a><br>Local UK Stockist</td>
    <td>
      Platinum
    </td>
    <td>
      <b>UK Based retailer, fast shipping. Modular purchase model:</b> buy one Base Kit per EMU system, then add one Lane Kit per lane required. Also excellent for existing kit expansion. <br><br>Kit includes EMU custom PCBs (hatch board and LED PCB), parts for stock EMUSync with option to add PSF, solo lane controller boards and IO Board separately. All optional boards (<a href="https://www.onetwo3d.co.uk/product/emu-solo-lane-board-slb/">Solo lane board</a>, <a href="https://www.onetwo3d.co.uk/product/psf-proportional-sync-feedback-sensor-for-mmu/">PSF</a>, <a href="https://www.onetwo3d.co.uk/product/emu-i-o-board/">EMU IO board</a>) stocked by OneTwo3D.<br/><br/>Kit includes pre-terminated wire looms, cut and crimped to size. Wiring for both SLB, EBB36/42 Gen 1, Gen 2, PSF and stock EMU Sync included. <br><br>Active support by the vendor in the Discord communities<br><br>Printed parts not included
    </td>
  </tr>
    <tr>
    <td><strong>Triangle Lab /</strong><br><strong>BLV</strong></td>
    <td><a href="https://aliexpress.com/item/1005012037255888.html">5 lane kit (trianglelab)</a>
    <br><br>
    <a href="https://aliexpress.com/item/1005012052899600.html">5 lane kit (BLV)</a><br><br>
      <a href="https://trianglelab.net/products/emu-5-lane-kit">5 lane kit (TL direct)</a>
    </td>
    <td>
      Silver
    </td>
    <td>
    Good quality core components kit requiring some additional wiring and assembly effort. Kit specifics:
    <ol>
      <li>⚠️ PRE-ASSEMBLED JST PLUGS: Take care to verify red and black wire locations. Initial shipments have these two wires swapped.</li>
      <li>Front switch PCB LED out wire is 300mm instead of 600mm. If using the Solo Lane Board, this is correct. If using an EBB, the user will need one additional WAGO, replacement of the 300mm LED out wire with a 600mm wire, or to solder the 300mm LED out wire to the 300mm LED in wire of the Hatch PCB.</li>
      <li>PCBs require soldering of the JST headers. All required JST headers and wires to assemble the kit are included.</li>
      <li>Wires are pre-crimped and assembled on the Box/front LED PCB connector side. The board side is uncrimped, but JST and Dupont crimps and plugs are provided. (See warning in point 1)</li>
      <li>WAGO alternatives are used. An alternative holder is required to be printed; the file is included in the usermod directory.</li>
      <li>Clear panel is 1.2mm thick. It is easier to assemble into place, with no expected impact on air-tightness.</li>
      <li>Sampled kit panel was 344mm instead of 343mm in length. Ensure the lid is correctly shrinkage compensated.</li>
      <li>Initial kits contain a Trianglelab-specific stepper. It provides higher torque at low speeds versus the BOM stepper, for example during printing, although maximum speed is limited to approximately 375mm/s. The stepper is planned to be swapped with the OMC BOM stepper in the future.</li>
      <li>One-way bearing and shaft, although hollow, are BOM-equivalent and showed correct, smooth motion.</li>
      <li>Stamped discs are included instead of demagnetised magnets for the Filamentalist sensors. These are functionally and dimensionally equivalent.</li>
      <li>Sampled kit did not include the M3x12 BHCS, or SHCS alternative. Subsequent kits should have this corrected.</li>
    </ol>
    </td>
  </tr>
<table>

### Controller Boards
In addition to the kit of your choice, one controller board per lane is required.
- **Recommended:** Solo lane board (SLB) [Ali Express](https://www.aliexpress.com/item/1005012025112049.html) [OneTwo3D](https://www.onetwo3d.co.uk/product/emu-solo-lane-board-slb/)- significantly simplifies wiring of the individual units.
- **Alternatively:** An EBB 42 or EBB 36 is also functional on the unit, with a bit more effort on crimping the necessary connectors.

### Certification Tiers
<table style="width: 100%;">
  <tr>
    <th style="width: 12%;">Tier</th>
    <th style="width: 18%;">User Experience</th>
    <th>Description</th>
  </tr>
  <tr>
    <td><strong>Platinum</strong></td>
    <td>The highest quality kit for the best user experience</td>
    <td>
      • It includes all core and optional BOM components at their highest possible quality with no tradeoffs.<br>
      • The mechanical components have excellent fit with limited/no re-work required by the end user.<br>
      • The kit includes all optional extras (PCB hatch boards, Eject button multi-LED board). Kit includes the Proportional Sync Feedback sensor and any additional PCBs that the kit vendor deems appropriate to ease assembly (eg. cable entry board)<br>
      • Wiring is pre-cut and crimped according to the universal wiring kit specifications / wiring guide. This means no crimping when using JST capable boards and limited crimping required when using EBB42/36 Gen 1 boards.<br>
      • All additional crimps and connectors as specified in the BOM are included in the kit enabling the widest array of boards to be used.
    </td>
  </tr>
  <tr>
    <td><strong>Gold</strong></td>
    <td>A high quality kit offering a good user experience</td>
    <td>
      • It includes all core and optional BOM components, with only minor tradeoffs in part selection where these do not materially affect functionality, reliability, or the overall build experience.<br>
      • The mechanical components have good fit, with potentially only minor re-work or adjustment required by the end user during assembly (eg. heat treating the one way bearing)<br>
      • The kit includes all optional extras (PCB hatch boards, Eject button multi-LED board). The Proportional Sync Feedback sensor may be omitted in lieu off a dual switch EMU Sync.<br>
      • Wiring is pre-cut and crimped according to the universal wiring kit specifications / wiring guide. This means no crimping when using JST capable boards and limited crimping required when using EBB42/36 Gen 1 boards.<br>
      • All additional crimps and connectors as specified in the BOM are included in the kit enabling the widest array of boards to be used..
    </td>
  </tr>
  <tr>
    <td><strong>Silver</strong></td>
    <td>A functional kit with a good but less refined user experience. Suitable for experienced builders who are comfortable with some additional build effort.</td>
    <td>
      • It includes the core BOM items required to complete a working build, but some optional extras or higher quality component choices may be omitted (eg. use of hollow steel tubes vs. solid, use of alternative stepper motors).<br>
      • The mechanical components are generally usable and will result in a functional build, but moderate re-work or adjustment may be required during assembly (eg. heat treating the one way bearing, de-magnetising the magnets manually).<br>
      • The kit may not include all optional extras, ie some of the PCBs may be omitted or come partly assembled, requiring the user to solder the JST connectors.<br>
      • Wiring may be only partially prepared, or supplied in bulk lengths that require the user to measure, cut, strip, and crimp a meaningful portion of the harness.<br>
      • Kit may omit some of the board connectors from the kit, requiring the user to supply their own JST/Dupont connectors to match their board selection
    </td>
  </tr>
  <tr>
    <td><strong>Bronze</strong></td>
    <td>A basic, barebones kit intended for the budget conscious users who are comfortable with the additional effort and extra troubleshooting that may be required. This tier represents the lowest level of maturity, completeness, and convenience.</td>
    <td>
      • It includes the core BOM items required to complete a working build, with lower cost substitutions present. There is the chance that some minor components may require the user to swap them during assembly due to tolerance/fitment issues (eg. magnets too big, rubber bands not precisely cut to fit the wheels).<br>
      • Some BOM items may not come prepared, ready for assembly - eg. panels may not be pre-cut to specification, instead supplied as larger sheets.<br>
      • PCB add-ons are not included, with the kit being a basic, printed only components build.<br>
      • Wiring is typically not pre-cut or pre-crimped, and the user should expect to complete most or all harness preparation themselves.<br>
      • Kit may omit some of the board connectors from the kit, requiring the user to supply their own JST/Dupont connectors to match their board selection
    </td>
  </tr>
</table>

**Manufacturers:** If you want to be included, please contact us. We are happy to validate your kit/parts, discuss licensing terms and then add you to the list.

### Self sourcing
While kits make sourcing convenient, the EMU can also be fully self sourced using [the provided Bill Of Materials](https://docs.google.com/spreadsheets/d/1jYJXBgpc_iLDfC17fC2LTYKrSEy5ocPbGEQ_EEOGCvI).

## Recommended Upgrades
While entirely optional, the below upgrades are highly recommended. 
1. [PCB hatch boards](/PCB%20(recommended%20options)/hatch_board) [AliExpress](https://www.aliexpress.com/item/1005011529532141.html), [OneTwo3D](https://www.onetwo3d.co.uk/product/emu-hatch-pcb-wiring-board-with-connectors/) - simplifies wiring, sealing of the box and reduces soldering need.
2. [Eject button multi-LED PCB](/PCB%20(recommended%20options)/multi_led_button) [AliExpress](https://www.aliexpress.com/item/1005011529532141.html) [OneTwo3D](https://www.onetwo3d.co.uk/product/emu-led-pcb-with-connectors/) - simplifies wiring and displays animated effects when loading / unloading filament.
3. Proportional Sync Feedback Sensor (PSF) [AliExpress](https://www.aliexpress.com/item/1005010470743517.html) [OneTwo3D](https://www.onetwo3d.co.uk/product/psf-proportional-sync-feedback-sensor-for-mmu/) - allows for clog, tangle detection and more accurate synchronisation between the EMU and the extruder.
4. Input / Output (IO) Board [AliExpress](https://www.aliexpress.com/item/1005011529532141.html) [OneTwo3D](https://www.onetwo3d.co.uk/product/emu-i-o-board/) - removes need to solder the XT30 2+2 and JST connector and simplifies wiring of the base IO.

---

← [Documentation Hub](/docs) | [Step 2: Printing, Assembly and Wiring →](/docs/assembly_wiring)

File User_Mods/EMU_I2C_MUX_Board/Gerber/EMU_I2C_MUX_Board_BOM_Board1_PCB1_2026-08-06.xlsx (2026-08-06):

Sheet: bom模板
 |  |  |  | Bill of Materials | EMU_I2C_MUX_Board_BOM_Board1_PCB1_2026-08-06
 |  |  |  | Project Title： | TCA9548A I2C复用
 |  |  |  | Variant:
 |  |  |  | Report Time： | 2026年8月6日 12:36:57
No. | Quantity | Comment | Designator | Footprint | Value | Manufacturer Part | Manufacturer | Supplier Part | Supplier | LCSC Price | Total
 | 1 | 100nF | C1 | C0603 | 100nF | CL10B104KB8NNNC | SAMSUNG(三星) | C1591 | LCSC
 | 1 | ZX-XH2.54-4PZZ | CN1 | CONN-TH_4P-P2.50_4PIN |  | ZX-XH2.54-4PZZ | Megastar(兆星) | C7429634 | LCSC
 | 8 | SH-XH2.54-4PZZ | CN2, CN3, CN4, CN5, CN6, CN7, CN8, CN9 | CONN-TH_4P-P2.50_BX-XH2.54-4PZZ |  | SH-XH2.54-4PZZ | SHOU HAN(首韩) | C54431935 | LCSC
 | 1 | PZ254V-11-01P | H1 | HDR-TH_1P-P2.54-V-M |  | PZ254V-11-01P | XFCN(兴飞) | C492400 | LCSC
 | 2 | 4.7kΩ | R1, R2 | R0603 | 4.7kΩ | FRC0603J472 TS | FOJAN(富捷) | C2907166 | LCSC
 | 1 | 10kΩ | R3 | R0603 | 10kΩ | FRC0603J103 TS | FOJAN(富捷) | C2930027 | LCSC
 | 1 | TCA9548APWR | U1 | TSSOP-24_L7.8-W4.4-P0.65-LS6.4-BL |  | TCA9548APWR | TI(德州仪器) | C130026 | LCSC

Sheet: Field汇总
Project Title | TCA9548A I2C复用
Borard Title | Board1
Schematic Title | Schematic1
PCB Title | PCB1
Variant Name
Total Quantity | 15
Report Time | 12:36:57
Report Date | 2026年8月6日
Report Date&Time | 2026年8月6日 12:36:57
File Name | EMU_I2C_MUX_Board_BOM_Board1_PCB1_2026-08-06
Filter Option | Add into BOM:no;

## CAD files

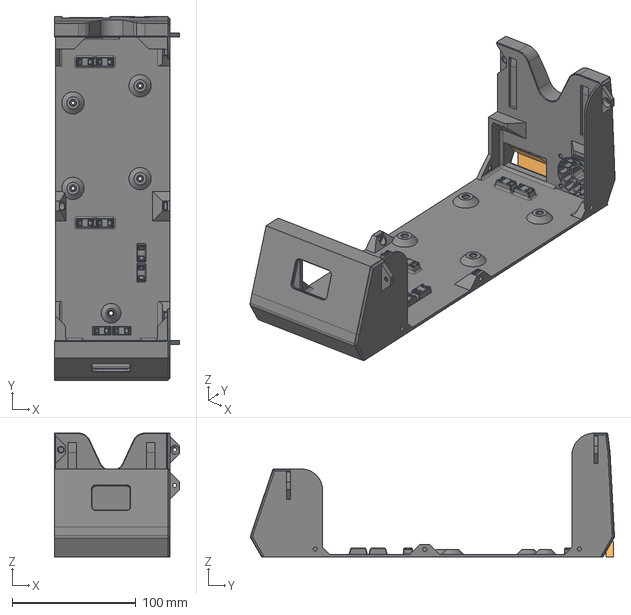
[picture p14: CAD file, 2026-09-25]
CAD/Multi_Lane_Base-Expander_with_rear_wire_opening.step
101.3 x 294.0 x 100.0 mm

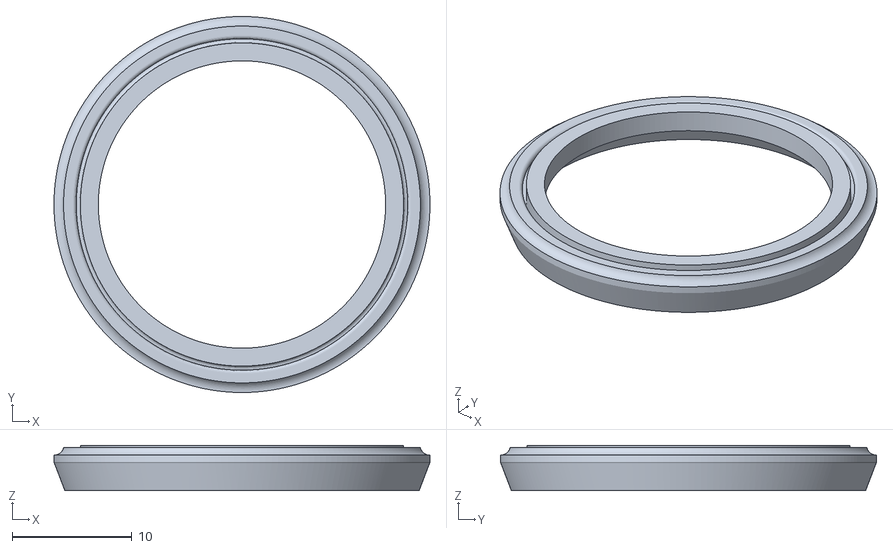
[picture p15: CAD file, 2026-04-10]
STL/Filamentalist/(Option) TPU_CDR/[TPU]_Half_Ring_Flex_1.65mm_x2.stl
31.4 x 31.4 x 3.80

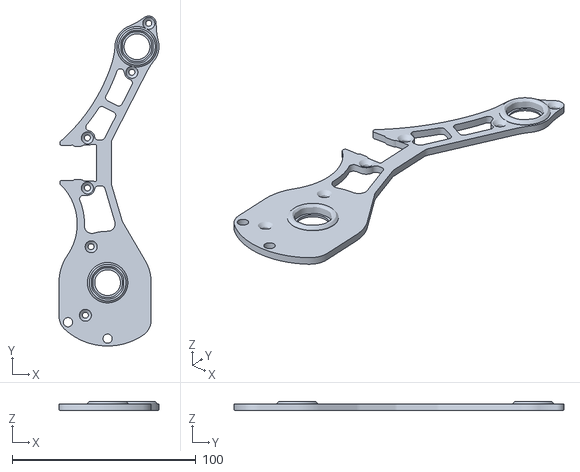
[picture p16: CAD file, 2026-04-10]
STL/Filamentalist/Chassis_R_688_Bearing.stl
54.5 x 179.7 x 5.00

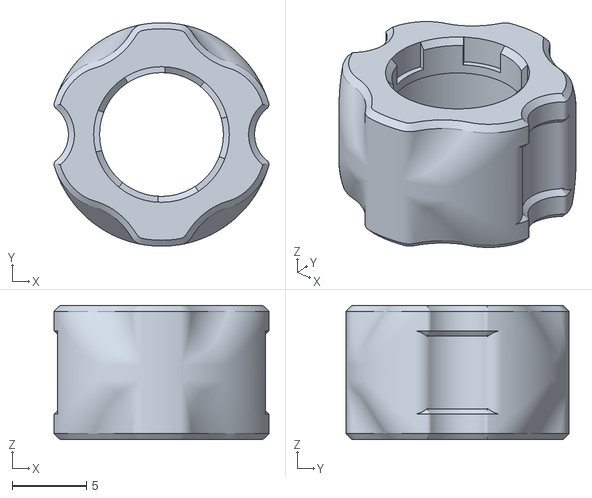
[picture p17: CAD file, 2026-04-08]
STL/Tension-compression-sensor/[a]_ECAS_trigger.stl
14.4 x 15.0 x 9.00

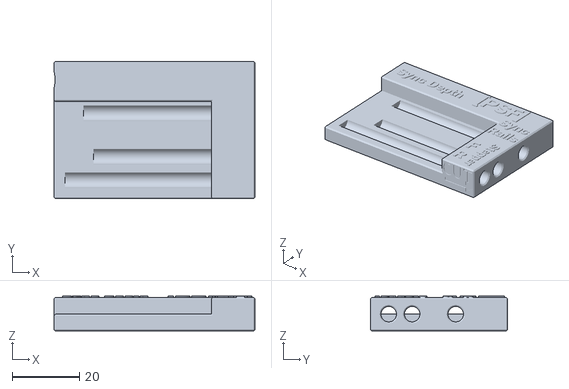
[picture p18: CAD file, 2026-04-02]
STL/Tools/PTFE Cutter and Length Tool[PSF].stl
60.0 x 41.0 x 10.4

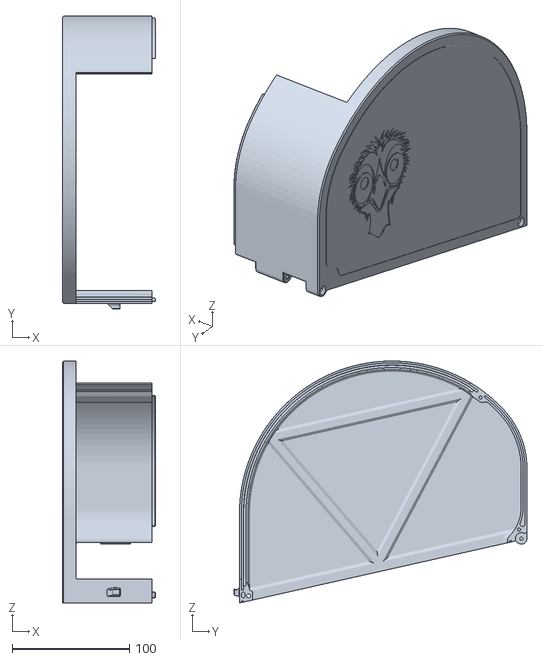
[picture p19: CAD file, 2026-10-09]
User_Mods/EMU_250mm_BuildPlate/250mm_adjusted_Lid.stl
79.1 x 249.6 x 206.1

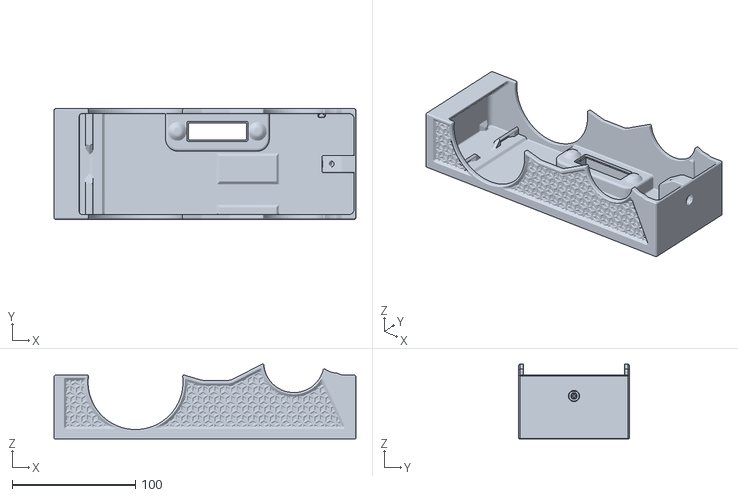
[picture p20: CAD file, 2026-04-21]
User_Mods/EMU_Convertible/STLs/EMU_convertible_closed_front-v1.1.stl
245.0 x 90.0 x 60.8

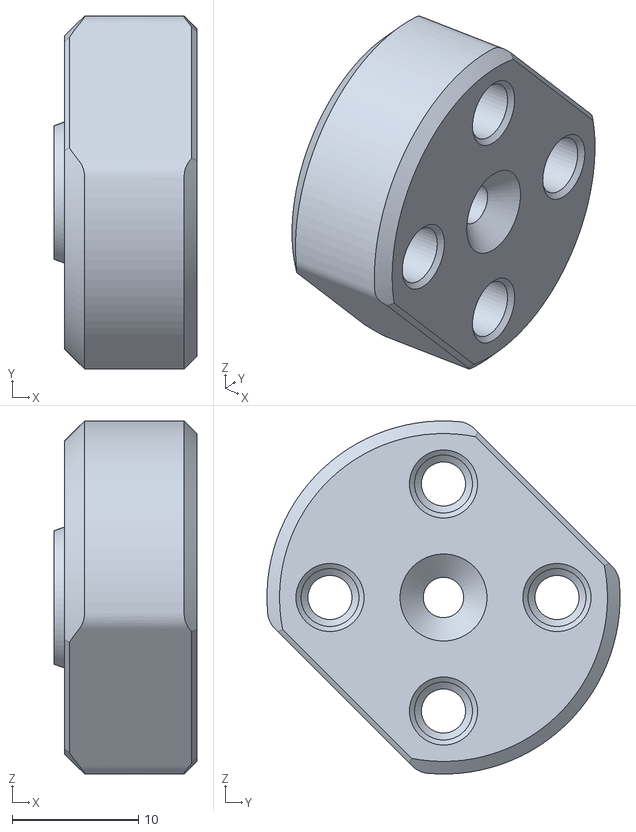
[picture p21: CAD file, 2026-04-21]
User_Mods/EMU_F1 Wheels/STL/Idler_roller_mount.stl
11.3 x 28.0 x 28.0

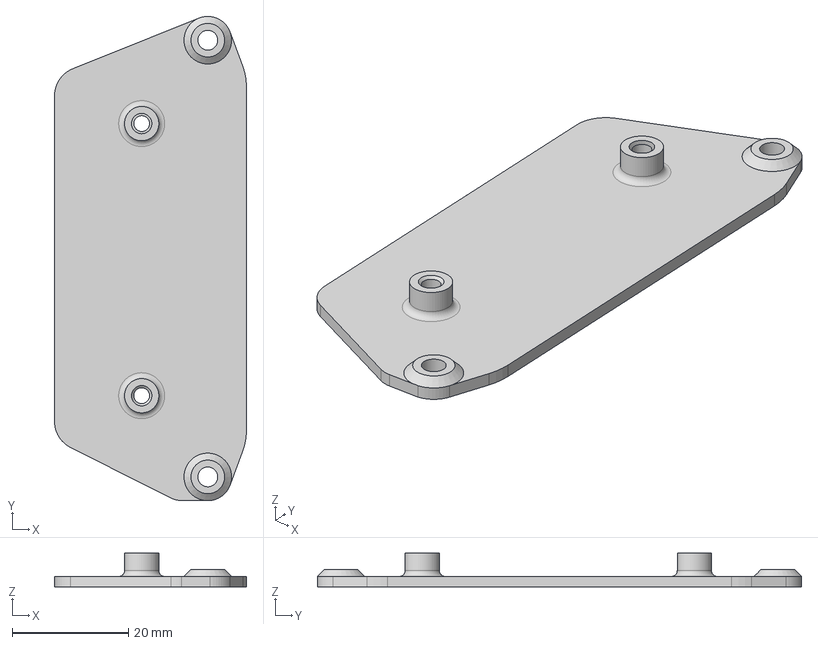
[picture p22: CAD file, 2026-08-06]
User_Mods/EMU_I2C_MUX_Board/CAD/EMU_I2C_MUX_Mount.step
33.0 x 83.2 x 5.80 mm

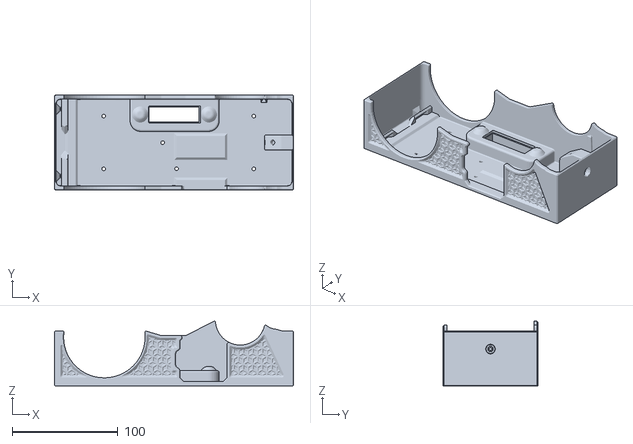
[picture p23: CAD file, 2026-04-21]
User_Mods/EMU_Lite/STL/EMU Lite - Open Nema Option-v1.1.stl
226.0 x 90.0 x 61.3

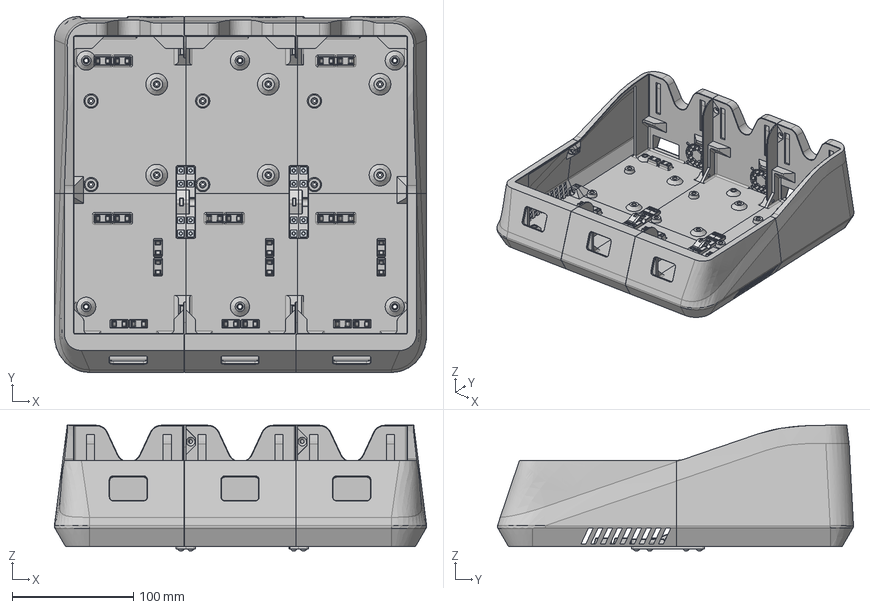
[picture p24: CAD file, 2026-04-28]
User_Mods/EMU_Split_base/CAD/EMU Split base.step
307.4 x 294.0 x 103.7 mm
Socket button head screw M3x0.5 x 8 x 16
Square thin nut grade B M3x0.5 x 16
Custom connector x 2

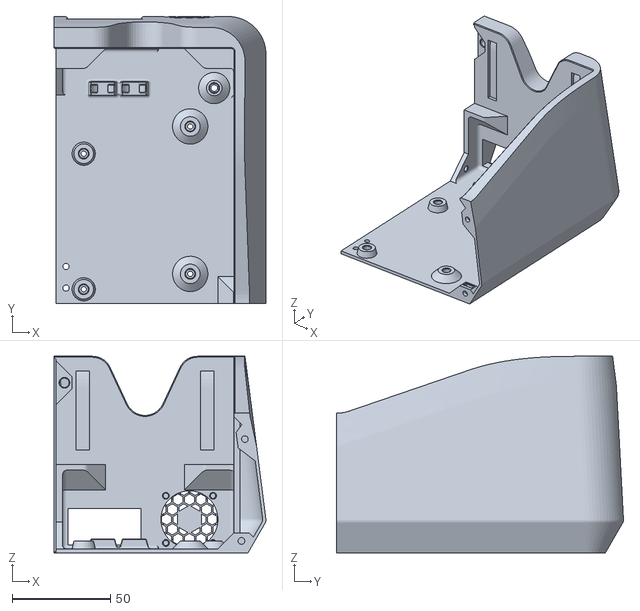
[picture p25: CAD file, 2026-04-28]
User_Mods/EMU_Split_base/STL/EMU_Split_base_Right_Rear.stl
107.8 x 146.0 x 100.0

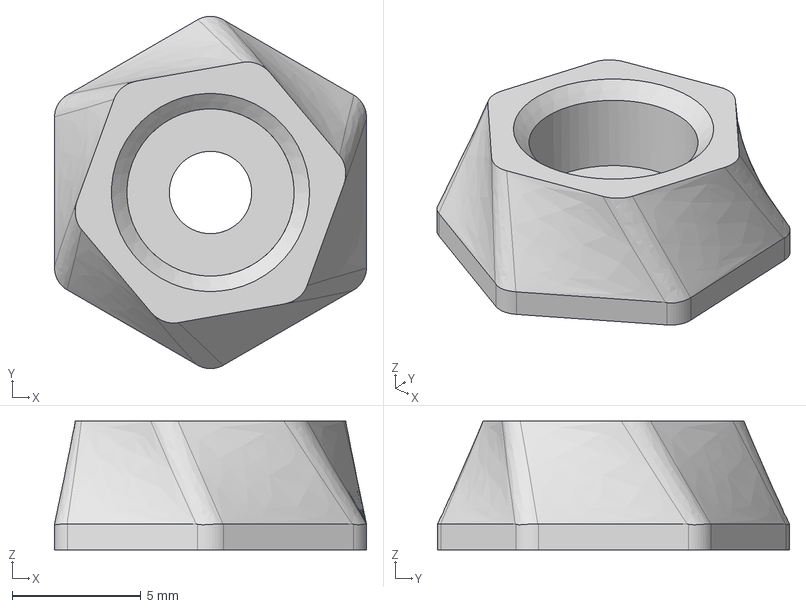
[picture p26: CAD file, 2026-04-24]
User_Mods/TPU_feet/CAD/hexagon_foot.step
12.1 x 13.7 x 5.00 mm

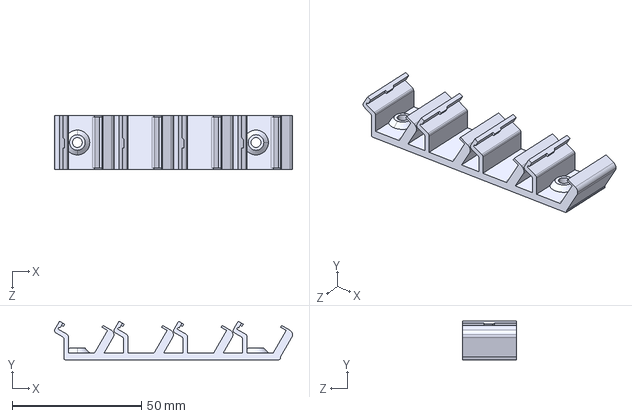
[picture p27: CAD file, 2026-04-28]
User_Mods/Trianglelab_BLV kit mods/[a]_PTC212-413_Holder (Wago221 alternative).step
91.9 x 14.9 x 21.0 mm

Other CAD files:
STL/Filamentalist/Chassis_L_688_Bearing.stl
STL/Tools/PTFE Cutter and Length Tool.stl
User_Mods/EMU_250mm_BuildPlate/250mm_adjusted_Latch.stl
User_Mods/EMU_Convertible/STLs/EMU_convertible_45front-v1.1.stl
User_Mods/EMU_Convertible/STLs/EMU_convertible_opened_front-v1.1.stl
User_Mods/EMU_F1 Wheels/STL/F1_Idler_Roller_Axle.stl
User_Mods/EMU_F1 Wheels/STL/Rim_Roller_Mount.stl
User_Mods/EMU_F1 Wheels/STL/[a]_F1_Idler_Roller_x2_74mm.stl
User_Mods/EMU_F1 Wheels/STL/[a]_F1_Idler_Roller_x2_84mm.stl
User_Mods/EMU_F1 Wheels/STL/[a]_F1_Rim_Roller_x2_74mm.stl
User_Mods/EMU_F1 Wheels/STL/[a]_F1_Rim_Roller_x2_84mm.stl
User_Mods/EMU_F1 Wheels/STL/[optional)_5mm_spacer_4x.stl
User_Mods/EMU_F1 Wheels/STL/[optional]_10mm_spacer_4x.stl
User_Mods/EMU_I2C_MUX_Board/CAD/EMU_I2C_MUX_Board_3D_PCB1_2026-08-06.step
User_Mods/EMU_I2C_MUX_Board/STL/EMU_I2C_MUX_Mount.stl
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

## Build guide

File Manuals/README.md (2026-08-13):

# EMU Assembly Manuals

This folder contains the step-by-step PDF assembly manuals for the EMU. The manuals are gradually replacing the [assembly videos](/docs/assembly_wiring/#assembly-videos) and are still a work in progress — new manuals are added here as they are finished.

They are meant to be read alongside the [Printing, Assembly and Wiring](/docs/assembly_wiring) page, which covers print settings, wiring and the printed parts configurator.

## Available Manuals

| Preview | Manual | Description |
|:---:|---|---|
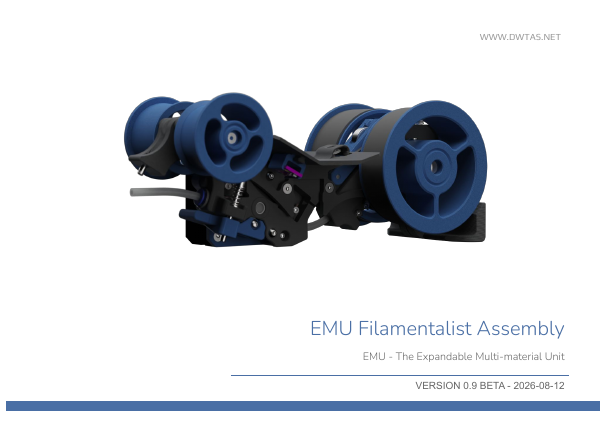
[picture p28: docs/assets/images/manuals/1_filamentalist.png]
| [](/Manuals/1_EMU_Filamentalist_Assembly_Manual.pdf) | **[1 – Filamentalist Assembly Manual](/Manuals/1_EMU_Filamentalist_Assembly_Manual.pdf)** | Building the filamentalist and lane stepper assembly. |
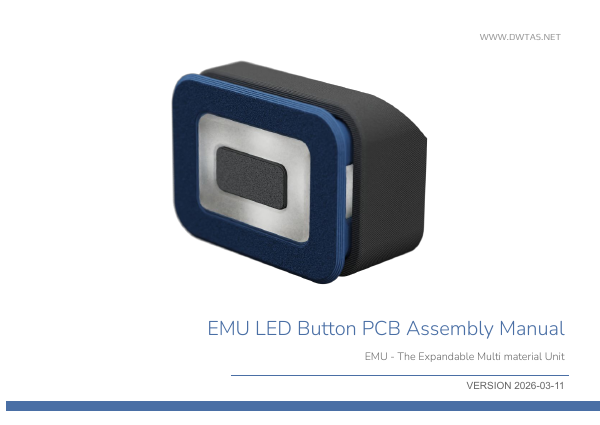
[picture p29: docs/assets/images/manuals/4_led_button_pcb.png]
| [](/Manuals/4_EMU_LED_Button_PCB.pdf) | **[4 – LED / Button PCB](/Manuals/4_EMU_LED_Button_PCB.pdf)** | Assembling the per-lane LED and eject button PCB. |
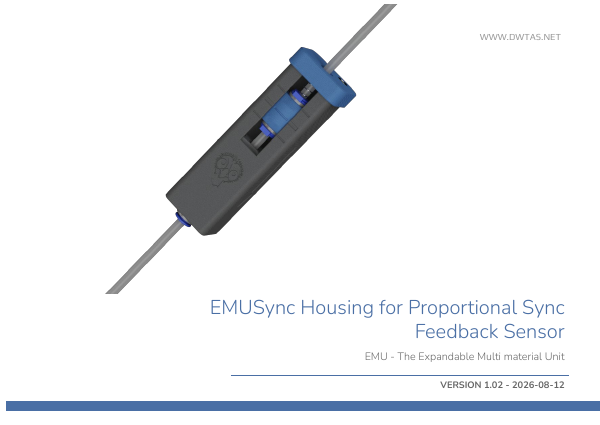
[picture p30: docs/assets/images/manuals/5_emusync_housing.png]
| [](/Manuals/5_EMUSync_Housing_for_Proportional_Sync_Feedback_Sensor.pdf) | **[5 – EMUSync Housing for the Proportional Sync Feedback Sensor](/Manuals/5_EMUSync_Housing_for_Proportional_Sync_Feedback_Sensor.pdf)** | Assembling the EMUSync housing that holds the proportional sync feedback (PSF) sensor. |

## In Progress

The remaining manuals are being written and will appear here as they are completed:

- 2 – Dry Box Assembly Manual
- 3 – Base Assembly Manual

## Acknowledgements

These manuals would not have been possible without [Martijn](https://github.com/martijnvanduijneveldt). A huge thank you to Martijn for all of his work in putting them together.

## Seeking Help

If you get stuck, the [Happy Hare Discord](https://discord.gg/aABQUjkZPk) is a great resource — both the general channel and the dedicated EMU channel.

---

[Documentation Hub →](/docs)

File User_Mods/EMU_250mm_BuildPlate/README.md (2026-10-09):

# EMU — 250 mm Build Plate Mod

### Dry box lid with a separate screw-on latch

A simple modification that allows the EMU dry box lid to be printed on a **250 mm build plate**. The integrated catch is removed from the lid and replaced with a separate printed latch, secured with an M2 screw and heat-set insert.

---

## Overview

The mod consists of two printed parts: a modified lid and a matching latch. Print both files below in place of the standard lid with its integrated catch.

### Modified lid

The lid has the integrated catch removed and includes mounting features for the separate latch.

<p align="center">
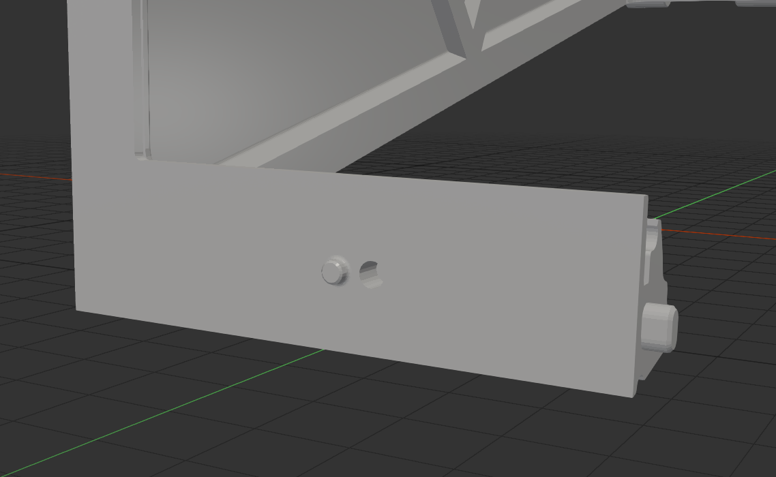
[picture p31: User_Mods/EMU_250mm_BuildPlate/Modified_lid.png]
Modified EMU dry box lid showing the mounting features for the separate latch
  
</p>

### Separate latch

The replacement latch attaches to the modified lid using the hardware listed below.

<p align="center">
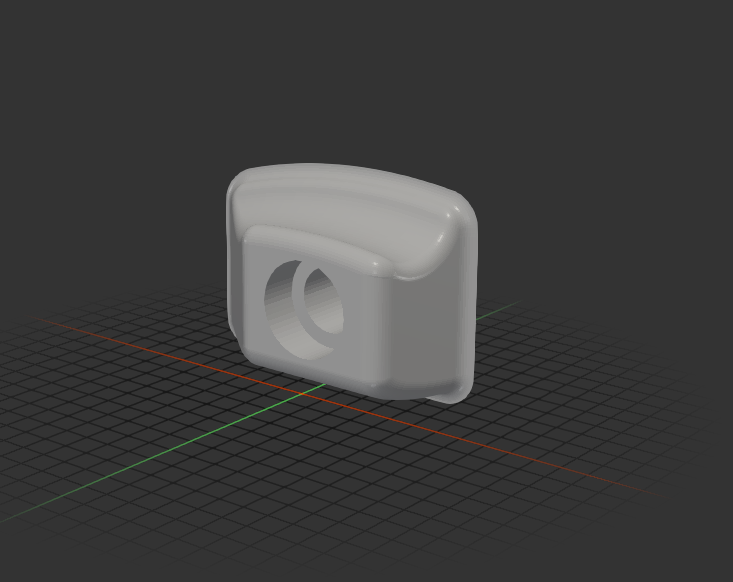
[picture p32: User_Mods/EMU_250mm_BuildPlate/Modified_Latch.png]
Separate printed latch showing its screw mounting hole
  
</p>

## Printed Parts

| Qty | Part | STL file |
| :---: | --- | --- |
| 1 | Modified dry box lid | [250mm_adjusted_Lid.stl](250mm_adjusted_Lid.stl) |
| 1 | Separate latch | [250mm_adjusted_Latch.stl](250mm_adjusted_Latch.stl) |

> [!TIP]
> Check the lid's orientation and total footprint in your slicer before printing. Allow room for any brim or skirt within your printer's usable build area.

## Bill of Materials

Additional hardware required **per lid**:

| Qty | Item |
| :---: | --- |
| 1 | M2 heat-set insert |
| 1 | M2 × 6 mm screw |

## Assembly

1. Print the modified lid and separate latch.
2. Install the M2.5 heat-set insert in the provided insert pocket and allow it to cool.
3. Align the latch with the mounting features on the lid.
4. Secure the latch with the M2 × 6 mm screw. Tighten until secure, taking care not to overtighten into the printed parts.
5. Check that the lid closes and the latch engages correctly before use.

---

[← Back to EMU](../../README.md)

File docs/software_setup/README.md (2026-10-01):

# EMU Software Setup

This section covers the software setup for the EMU. The EMU needs MMU control software running alongside Klipper. Both of the options below support the EMU natively. The EMU was developed on Happy Hare and it's the software we have the most experience with. However, AFC is equally an option if you prefer it or already use it, with its setup covered in the AFC documentation.

- **Happy Hare v4:** The main installation guide is the [EMU Getting Started guide](https://moggieuk.github.io/Happy-Hare-Doc/GettingStarted-EMU/) in the [Happy Hare documentation](https://moggieuk.github.io/Happy-Hare-Doc/). The Happy Hare pages below cover what's specific to the EMU.
- **AFC (AFC-Klipper-Add-On):** Follow the [AFC documentation](https://www.afcproject.dev/), starting with the [Initial Startup & Commissioning guide](https://www.afcproject.dev/initial-startup/01-overview.html) (select the EMU tab). In the AFC installer, choose **EMU** as the unit type.

Board setup and UKAM apply whichever option you choose. The Happy Hare section of Software Setup, Calibration and Startup, Expanding the Unit and the slicer machine G-code are written for Happy Hare. The board setup step also references [Esoterical's CANBus setup](https://canbus.esoterical.online).

> [!NOTE]
> **Still on Happy Hare v3?** The previous v3 guides are kept in the [legacy Happy Hare v3 archive](/docs/software_setup/legacy_hhv3), along with how to stay on v3 or upgrade to v4.

## Table of Contents

- [EMU Board Setup](/docs/software_setup/01-board-setup.md)
  - [Setting up CAN Bus](/docs/software_setup/01-board-setup.md#setting-up-can-bus)
  - [Setting up the Solo Lane Boards](/docs/software_setup/01-board-setup.md#setting-up-the-solo-lane-boards)
  - [Setting up and flashing the EBB boards](/docs/software_setup/01-board-setup.md#setting-up-and-flashing-the-ebb-boards)
  - [Updating the boards with the latest klipper version](/docs/software_setup/01-board-setup.md#updating-the-boards-with-the-latest-klipper-version)
- [Software Setup](/docs/software_setup/02-software-setup.md)
  - [Happy Hare v4](/docs/software_setup/02-software-setup.md#happy-hare-v4) – [Getting Started with EMU (Happy Hare v4)](https://moggieuk.github.io/Happy-Hare-Doc/GettingStarted-EMU/)
    - [EMU notes for the v4 installer](/docs/software_setup/02-software-setup.md#emu-notes-for-the-v4-installer)
    - [After installing](/docs/software_setup/02-software-setup.md#after-installing)
  - [AFC (AFC-Klipper-Add-On)](/docs/software_setup/02-software-setup.md#afc-afc-klipper-add-on)
- [Calibration and Startup](/docs/software_setup/03-calibration-and-startup.md)
  - [First start up](/docs/software_setup/03-calibration-and-startup.md#first-start-up)
  - [Calibrating the unit](/docs/software_setup/03-calibration-and-startup.md#calibrating-the-unit)
    - [Check the calibration settings](/docs/software_setup/03-calibration-and-startup.md#check-the-calibration-settings)
    - [Calibrate the EMU Sync PSF sensor (PSF only)](/docs/software_setup/03-calibration-and-startup.md#calibrate-the-emu-sync-psf-sensor-psf-only)
    - [Bowden length auto-calibration](/docs/software_setup/03-calibration-and-startup.md#bowden-length-auto-calibration)
    - [Toolhead dimensions](/docs/software_setup/03-calibration-and-startup.md#toolhead-dimensions)
  - [Manual unit calibration (optional - if not satisfied with automated calibrations)](/docs/software_setup/03-calibration-and-startup.md#manual-unit-calibration-optional---if-not-satisfied-with-automated-calibrations)
    - [Lane rotation distance calibration](/docs/software_setup/03-calibration-and-startup.md#lane-rotation-distance-calibration)
    - [Bowden tube calibration](/docs/software_setup/03-calibration-and-startup.md#bowden-tube-calibration)
- [Expanding the Unit](/docs/software_setup/04-expanding-the-unit.md)
- [Slicer Setup and Optimisation for Multi Color Prints](/docs/software_setup/05-slicer-setup.md)
  - [Orca slicer mandatory setup](/docs/software_setup/05-slicer-setup.md#orca-slicer-mandatory-setup)
  - [Orca slicer profile tuning for multi-color printing](/docs/software_setup/05-slicer-setup.md#orca-slicer-profile-tuning-for-multi-color-printing)
- [Updating CAN Boards with UKAM](/docs/software_setup/06-updating-can-boards.md)
- [Manual Sensorless Toolhead Calibration for Happy Hare](/docs/software_setup/07-manual-toolhead-calibration.md)
- [Manual Toolhead Calibration with Two Sensors for Happy Hare](/docs/software_setup/08-manual_toolhead_calibration_two_sensors.md)
- [Legacy Happy Hare v3 guides (archive)](/docs/software_setup/legacy_hhv3)

## After Setup
Once you have completed the steps above you should have a fully working EMU. You can optionally also set up:
1. [KlipperScreen integration](https://moggieuk.github.io/Happy-Hare-Doc/KlipperScreen/)
2. [Mainsail / Fluidd MMU panel](https://moggieuk.github.io/Happy-Hare-Doc/Mainsail-Fluidd-Integration/)
3. [Spoolman support](https://moggieuk.github.io/Happy-Hare-Doc/Feature-Spoolman/)

## Seeking Help

If you get stuck, the [Happy Hare Discord](https://discord.gg/aABQUjkZPk) is a great resource — both the general channel and the dedicated EMU channel.

---

← [Documentation Hub](/docs)

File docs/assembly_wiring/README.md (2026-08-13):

# EMU – Printing, Assembly and Wiring

This page covers printing the parts, assembling the EMU and wiring the electronics. It is meant to be read in conjunction with the assembly videos linked below.

## Configurator
Use the [configurator linked here](https://emu.dwtas.net) to select your number of lanes and build options and download the necessary STL's for your EMU build.

## Table of Contents
- [EMU – Printing, Assembly and Wiring](#emu--printing-assembly-and-wiring)
  - [Configurator](#configurator)
  - [Table of Contents](#table-of-contents)
  - [Print Settings](#print-settings)
    - [Filamentalist components and Lane stepper components](#filamentalist-components-and-lane-stepper-components)
    - [Dry Box components](#dry-box-components)
    - [Base unit components](#base-unit-components)
  - [Assembly Manuals](#assembly-manuals)
  - [Assembly Videos](#assembly-videos)
    - [Part 1: Filamentalist and Stepper Assembly Guide](#part-1-filamentalist-and-stepper-assembly-guide)
    - [Part 2: Drybox Assembly Guide](#part-2-drybox-assembly-guide)
    - [Part 3: Base Assembly Guide](#part-3-base-assembly-guide)
    - [Part 4: Electronics Assembly Guide](#part-4-electronics-assembly-guide)
    - [Part 5: EMU Sync Assembly images](#part-5-emu-sync-assembly-images)
    - [Combiner:](#combiner)
  - [Wiring Instructions and Diagrams](#wiring-instructions-and-diagrams)
  - [Wiring key dimensions](#wiring-key-dimensions)
    - [Base wiring dimensions](#base-wiring-dimensions)
    - [PCB Hatch wiring dimensions](#pcb-hatch-wiring-dimensions)
    - [DIY Hatch (no pcb) wiring dimensions](#diy-hatch-no-pcb-wiring-dimensions)
    - [Solo Lane Board (SLB) wiring dimensions](#solo-lane-board-slb-wiring-dimensions)

<p align="center">
  
</p>

## Print Settings

> [!WARNING]
> **Parts are not shrinkage compensated** - calibrate your filament shrinkage first! 

### Filamentalist components and Lane stepper components:
The below print settings are recommended for the filamentalist and lane stepper components. These are structural parts hence require print settings optimised for strength:
- 0.2 mm layer height
- 0.2 mm first layer height
- 4 walls
- 40% infill
- 0.4mm extrusion width (line width) throughout
- Gyroid sparse infill is recommended as it tends to warp less
- Inner Outer wall ordering, to ensure overhangs and supported areas do not sag
- Arachne wall generator
- One wall top and bottom surfaces (optional but recommended - parts look nicer)
- Disable thick bridges
- Z hop enabled to avoid nozzle scraping (0.2 is sufficient)

> [!IMPORTANT]
> If the bearings are loose, you're either under extruding, or over compensating for shrinkage.<br/>

> [!IMPORTANT]
> The [Idler_Roller_Axle](https://github.com/DW-Tas/EMU/blob/main/STL/Filamentalist/Idler_Roller_Axle.stl) and [[a]_Stepper_Tension_Arm](https://github.com/DW-Tas/EMU/blob/main/STL/Stepper/%5Ba%5D_Stepper_Tension_Arm%5BMR693zz%5D.stl) are best to be printed with **999 walls** to ensure adequate strength of the part and less chance of breakage.

> [!IMPORTANT]
> **Disable thick bridges** in your slicer and make sure your flow rate (EM) is on point! **Over extrusion, thick bridges and insufficient cooling will cause your sensor magnets and bearings not to fit as the bridges will sag.**

**For the TPU filamentalist CDR ring:**
- 0.2 mm layer height
- 0.2 mm first layer height
- 0.4mm extrusion width (line width) throughout
- 6 walls, so that the object is printed solid
- Avoid crossing walls enabled
- Random seam. This is important to avoid an aligned seam bump
- Inner Outer wall ordering, to ensure overhangs and supported areas do not sag
- Z Hop turned off to reduce stringing
  
> [!IMPORTANT]
> Printing TPU can be a challenge - print by object and a slight negative (-0.1) extra length on retract can help reduce stringing.

### Dry Box components:
The below print settings are recommended for the dry boxes and the desiccant holder. The dry boxes need to be as air tight as possible, hence the recommended print settings below are tuned to achieve this while keeping filament use under control.
- 0.2 mm layer height
- 0.2 mm first layer height
- 3 walls
- 15% infill
- For the lid specifically, use 4 walls and 30% infill to ensure strength in the front lip.
- 0.4mm extrusion width (line width) throughout
- Gyroid sparse infill is recommended as it tends to warp less
- Inner Outer wall ordering, to ensure dry box hatch features print with minimal sagging.
- Arachne wall generator
- One wall top and bottom surfaces (optional but recommended - parts look nicer)
- Disable thick bridges
- Z hop enabled to avoid nozzle scraping (0.2 is sufficient)

> [!IMPORTANT]
> Print with **extra first layer squish, use an adhesion promoter on the bed and in a pre-heated chamber with low fan** to prevent warping and ensure better layer adhesion. Mouse ears on the box corners may be required. Slight lifting will not impact part function.<br/>
> **Do not use mouse ears on the lid** as the slicer wrongly fills in the aesthetic lines.<br/>
> **Over extrude (only) the box and lid by ~2% (0.02)** to ensure air tightness. Increase your slicer flow multiplier (EM) by 0.02.

### Base unit components:
The below print settings are recommended for the base units and their accessories. 
- 0.2 mm layer height
- 0.2 mm first layer height
- 3 walls
- 15% infill
- 0.4mm extrusion width (line width) throughout
- Gyroid sparse infill is recommended as it tends to warp less
- Inner Outer Inner wall ordering to improve visual appearance
- Arachne wall generator
- One wall top and bottom surfaces (optional but recommended - parts look nicer)
- Disable thick bridges
- Z hop enabled to avoid nozzle scraping (0.2 is sufficient)
- For the **Eject button lens, 99 walls are recommended,** to reduce possibility of infill shining through the natural ABS

> [!IMPORTANT]
> Print with **extra first layer squish, use an adhesion promoter on the bed and in a pre-heated chamber with low fan** to prevent warping. Slight lifting will not impact part function.

> [!NOTE]
> **Paint on fuzzy skin** on the outer walls of the base unit will improve appearance.<br/>
> Paint on ONLY, not full model fuzzy skin. <br/>
> 0.1 distance, 0.1 or 0.2mm depth. Displacement method (orca slicer)

## Assembly Manuals
Assembly manuals are gradually becoming available in the [Manuals folder](/Manuals), replacing the assembly videos below.

## Assembly Videos

### Part 1: Filamentalist and Stepper Assembly Guide
EMU Filamentalist and Stepper Assembly Guide (https://www.youtube.com/watch?v=FNcXC9HXUmI)
<br/>
**Errata:**
1. BMG Gear insertion is not visible in the video. Do this before adding the stepper main body and screwing it on.
2. Switch sensor screws are M2x10 self-tapping
3. Filament path - BMG gear alignment step is not shown in the video. Insert some filament through the unit manually, loosen the BMG gear set screw and move it back and forth. Screw down the BMG gear.
4. For the BMG tensioning arm, the bushing is no longer an option. 
5. Add a washer to the stepper tensioning arm on both sides of the spring.
6. Add a washer to the filamentalist tensioning arm on both sides of the spring.
7. Stepper body screws are all M3x20. Stepper wiring comes out the front, not the rear as shown in the video.
8. Front ECAS is no longer required
9. PTFE tube lengths have been updated since the video release. [Use the dedicated cutter STL](https://github.com/DW-Tas/EMU/blob/main/STL/Tools/PTFE%20Cutter%20and%20Length%20Tool.stl) to measure and cut the PTFE tubes.
10. Front wheels now use a single M3x12 FHCS screw with a square nut placed in the corresponding wheel slot.
11. Insert the front PTFE tube while assembling the body, not after as shown in the video.

### Part 2: Drybox Assembly Guide
EMU Dry Box Assembly Guide (https://www.youtube.com/watch?v=JZzMyOBCdSM)
<br/>

**Errata:**
1. A threaded stand off is inserted in the front lip of the lid and secured from either side with M3x40 FHCS bolts.
2. Box and wiring hatch changes - the wiring hatch now is screwed in from the outside of the unit. Push through the hole from the inside out and then screw in place.
3. Wiring hatch foam is now glued on the box itself. The foam chord channel is on the outside of the box. 
4. The BME sensor has been relocated to the LED cover.

### Part 3: Base Assembly Guide
EMU Base Assembly Guide (https://www.youtube.com/watch?v=2SmAMuXas38)
<br/>
**Errata:**
1. Base unit top clamping screws (M3x8 FHCS) now screw into heatset inserts inserted on the other side of the frame.
2. The board and wago connectors now thread into heatset inserts from the top of the unit.

### Part 4: Electronics Assembly Guide
EMU Electronics Assembly Guide (https://www.youtube.com/watch?v=Iang2JYkTh8)
<br/>

**Errata:**
1. Base unit top clamping screws (M3x8 FHCS) now screw into heatset inserts inserted on the other side of the frame.
2. External combiner sensor is no longer required. That wiring part can be omitted.
3. Encoder is no longer required in the default setup. That wiring part can be omitted.
4. In the video, LED wiring is performed using the legacy method where a single LED chain was being created tied to the first EBB board. Current wiring approach wires each lane's LED's to the corresponding lane EBB, effectively moving away from one chain to N chains, where N is the number of lanes in the system. This simplifies wiring greatly and contains the wiring for each lane within the lane itself.
5. CANbus entry wires (Yellow/Green) are now connected directly to the first lane EBB42/36, omitting the WAGO connectors. Only the power wires and LED signal wire are now connected to the WAGO connectors.

### Part 5: EMU Sync Assembly images
<table>
  <tr>
    <td>Step 1</td>
    <td>Step 2</td>
    <td>Step 3</td>
  </tr>
  <tr>
    <td>Step 4</td>
    <td>Step 5</td>
    <td>Step 6</td>
  </tr>
  <tr>
    <td>Step 7</td>
    <td>Step 8</td>
    <td>Step 9</td>
  </tr>
  <tr>
    <td>Step 10</td>
    <td>Step 11</td>
    <td>Step 12</td>
  </tr>
  <tr>
    <td>Step 13</td>
    <td>Step 14</td>
    <td>Step 15</td>
  </tr>
</table>

### Combiner:
Make sure the PTFE tube is pushed all the way inside the combiner. Not just at the ecas entry!



## Wiring Instructions and Diagrams
Depending on the number of lanes assembled, the wiring will vary slightly. Below are some initial wiring key notes to get your started.<br/>

**Wiring notes**
1. Please note that the sync feedback sensor is connected to the first lane board.
2. The CAN bus umbilical from the printer feeds power and the CAN H / L wires to the WAGO connectors in the first lane. 
3. A 24V and Ground "bus" is established throughout the base unit using the two rear WAGO connectors (WAGO 3 and WAGO 4).
4. The EBB boards connect to the power bus for power and plugged in using their Molex ports.
5. The EBB boards are daisy chained to establish the CANbus network. The first lane canbus High / Low are connected to the box cable entry and power from the first lane WAGOs (wago 3 and 4).
7. The second lane canbus High / Low wires are connected to the CAN out dupont connectors on the first board itself. This creates the daisy chain.
9. The last EBB board needs the 120Ohm resistor installed.
10. Each lane's 2nd WAGO connector is used to connect the Neopixel Out wire from the eject button to the Neopixel In wire on the dry box.

**Adding a second base unit** <br/>
You can daisy chain as many base units as you desire. Simply wire the XT30+2 CAN out port next to the last lane to the power bus and CAN H / L dupont connectors on the last EBB board. The next base unit can connect using a standard CAN Bus cable to the first unit.

**EBB 42 wiring diagram**<br/>
<p align="center">
  
</p>

**Printer PSU**<br/>
> [!WARNING]
> You need to evaluate whether your PSU has enough power headroom. This entirely depends on your printer's overall setup. Ideally **plan for ~20 Watts for an 5 lane MMU** with **each additional lane requiring approximately an additional ~2-2.5 Watts.**

Key factors to consider:
1. PSU wattage
2. How many A-B/X-Y and Z steppers 
3. At what current the main printer steppers are operating at and what print speeds you operate them at
4. Your heater cartridge wattage 
5. What other power consuming accessories are connected to the printer (cpap, heater bed if 24V etc)

Depending on the combined power consumption, you may need to consider whether a PSU upgrade is needed. 

As a rule of thumb, a 12 lane EMU build with 4 Z steppers and 2 AB steppers running moderately high currents and high print speeds on a Voron 2.4 may require a 350Watt power supply to ensure adequate power headroom.

## Wiring key dimensions

This parts describes the recommended wire length for easy assembly and maintenance.

### Base wiring dimensions

<p align="center">
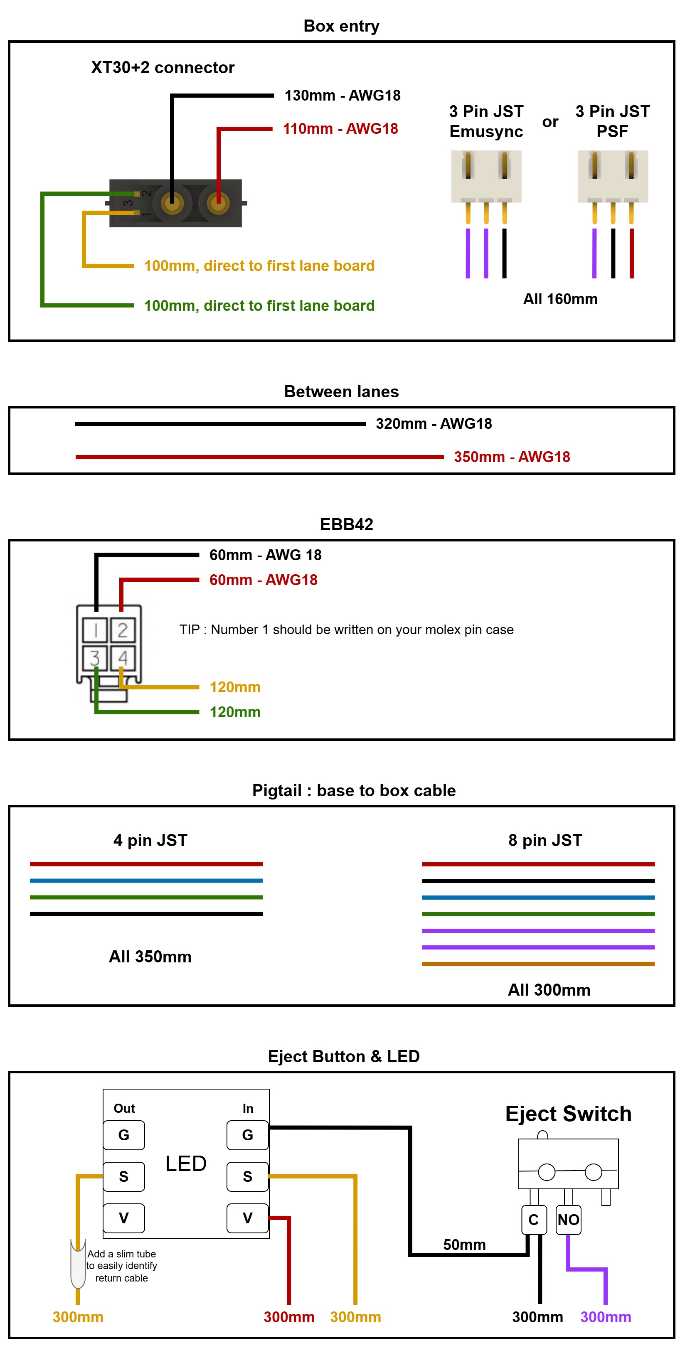
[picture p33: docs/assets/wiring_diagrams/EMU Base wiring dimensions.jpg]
  
</p>

### PCB Hatch wiring dimensions
These dimensions are for the latest version of the PCB (Post sensor at the rear). If you have the older board (Post Sensor at the center) [refer to this image](/docs/assets/wiring_diagrams/EMU%20PCB%20Hatch%20wiring%20dimensions%20-%20Old%20PCB.jpg) for sensor wire lengths.
<p align="center">
  
</p>

### DIY Hatch (no pcb) wiring dimensions
These wiring dimensions assume you mount the BME sensor on the led cover and connect `5V` and `Ground` of the BME sensor to the led out `5V` and `Ground`.

<p align="center">
  
</p>

### Solo Lane Board (SLB) wiring dimensions
The Solo Lane Board uses a much simpler wiring arrangement. Key dimensions outlined below
1. 4 pin stepper connector from Box to SLB - **300mm**
2. 8 pin box connector from Box to SLB - **300mm**
3. 5 pin front LED PCB connector to SLB - **300mm**
4. Between lanes power connection (SLB - SLB) - **60mm** (power and ground - AWG18)
5. Between lanes CANBus connection (SLB - SLB) - **70mm**
6. Wiring dimensions inside the box (3x filament sensors, Temp and Humidity sensor, Stepper, Neopixel) **remain the same as above**

Entry PCB to first Solo Lane Board
1. Power:
2. CANBus:
3. Sync Feedback (PSF/Switch Based):



---

← [Step 1: Sourcing](/docs/sourcing.md) | [Step 3: EMU Board Setup →](/docs/software_setup/01-board-setup.md)

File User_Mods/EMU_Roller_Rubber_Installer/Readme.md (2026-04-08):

# EMU Roller bike tire cutter and installer jig
 
**BOM:** </br>
Requires a pack of zipties - minimum 3.5mm through to 5mm wide.
 
**Cutter:** <br/>
Slip the tube over the cutter guide and use a pair of scissors to trim both edges. I found 30mm wide was enough for my tube but you can scale the stl to suit the coverage of the tube you receive.
 
1:
2:
3:
4:
 
**Tube installer:** After installing one set and fighting with the tube I created a quicker way to get the tube on the rum without skinning your knuckles. If you are good with a sharp object you can reuse the zipties across a couple of tubes by releasing them. I could get 4 rims done off a set of 4 on average. If you want to get it done quickly simply snip the cable ties once the rubber is on the rim.
<br/><br/>
Install the first two zipties - notice the orientation of the ziptie to assist with stretching.
1:
<br/>
Add the next two zipties
2:
<br/>
Slowly stretch to size - use the roller as a guide if you need to. You can get away with slightly smaller then the rim and simply push it over the edge.
3:
<br/>
Slip it on the roller
4:
<br/>
Either use a sharp object (carefully) to unlock the ziptie and undo or use a pair of snips and cut them
5:
<br/>
Slowly pull the zipties from under the tube. Careful not to split/cut the tube at this stage
6:
<br/>
Rolled rubber on the roller.
7:
<br/>
Unroll the rubber and shift around to cover the roller.
8:
<br/>
All done - now assemble onto your EMU!

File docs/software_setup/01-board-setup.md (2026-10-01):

# EMU Board Setup

This section covers flashing Katapult and Klipper to the EBB boards over CAN bus. It applies whichever MMU software you use (Happy Hare v4, Happy Hare v3 or AFC), and is meant to be read in conjunction with that software's documentation: the [Happy Hare documentation](https://moggieuk.github.io/Happy-Hare-Doc/) or the [AFC documentation](https://www.afcproject.dev/).

## Table of Contents

- [Setting up CAN Bus](#setting-up-can-bus)
- [Setting up the Solo Lane Boards](#setting-up-the-solo-lane-boards)
- [Setting up and flashing the EBB boards](#setting-up-and-flashing-the-ebb-boards)
- [Updating the boards with the latest klipper version](#updating-the-boards-with-the-latest-klipper-version)

## Setting up CAN Bus
If your printer does not have canbus set up, follow the excellent guide from Esoterical here: https://canbus.esoterical.online. If you are not familiar with CAN Bus, read through the guide from Esoterical. **CAN Bus is simple to set up and operate, but please do read the guide to familiarise yourselves with the CAN Bus concepts and terminology.**

Do not forget to terminate the last EBB board or CANBus device in your bus (depending on your bus topology).

## Setting up the Solo Lane Boards
The Solo Lane Boards for EMU come pre-flashed with katapult and klipper. This guide can be skipped and instead
1. Install the boards
2. Power on - double press the first lane reset button
3. In mainsail-> Machine -> Devices -> CAN0 hit refresh
4. Note the UUID of the device that is in flagged as katapult
5. Click reset again
6. Repeat for all lanes, taking note of the UUIDs

## Setting up and flashing the EBB boards
Prior to setting up the EMU, the EBB boards need to be flashed with Katapult and Klipper. Flashing instructions can be found here https://canbus.esoterical.online/toolhead_flashing.html. The boards are flashed in exactly the same way as if they were used as a toolhead board. Below are some high level instructions; however do refer back to the guide by Esoterical for a more comprehensive guide.<br/>

**Step 1:** Install katapult:<br/>
Katapult is a piece of software that sits on the EBB units (and any CAN Bus device) and acts as an easy way to set your board in "flashing mode" making klipper updates super easy. It is highly recommended that Katapult is flashed on the boards.
```bash
test -e ~/katapult && (cd ~/katapult && git pull) || (cd ~ && git clone https://github.com/Arksine/katapult) ; cd ~
```
**Step 2:** Connect your first EBB board over USB **outside the EMU**. Make sure the **power by USB jumper is set**.<br/>
**Step 3:** Set the board in DFU mode by pressing and holding the reset and boot buttons. Release the reset button first, then release the boot button<br/>
**Step 4:** The board should show as in DFU mode. Run ```lsusb``` and check that something like the below is shown in the command line:<br/>
```bash
Bus 001 Device 005: ID 0483:df11 STMicroelectronics STM Device in DFU Mode
```
**Step 5:** initiate menuconfig for Katapult.<br/>
```bash
cd ~/katapult
make menuconfig
```


```bash
make
```
**Step 6:** Flash katapult to the EBB board<br/>
```bash
sudo dfu-util -R -a 0 -s 0x08000000:mass-erase:force:leave -D ~/katapult/out/katapult.bin -d 0483:df11
```
**Step 7:** initiate menuconfig for klipper and make the firmware<br/>
```bash
sudo service klipper stop
cd ~/klipper
make clean
make menuconfig
```

```bash
make
```
**Step 8:** Prepare to flash klipper<br/>
Now that katapult is loaded, unplug the USB cable, remove the USB power jumper (if installed) and install the EBB on the unit. Power it via the canbus pigtail.

Please note, **you can set up katapult on all the boards and install them back to the unit all at once**. However, identifying which board is which from the UID is more tricky if you have them all installed in the unit. 

You have two options to identify them.
1. Unplug the positive (red) wire from the wagos for all the boards except the one you are intending to flash klipper, Run the command from Step 9, note the UUID, flash klipper and note down the UUID you just used with the lane number in your documentation  _--or--_
2. Run the command from Step 9, pick one UUID, flash Klipper, note which board's led stopped flashing and note down the UUID you just used with the lane number in your documentation.

**Step 9:** Find the board UUID<br/>
Run the command below and note the produced UUID
```bash
python3 ~/katapult/scripts/flashtool.py -i can0 -q
```
**Step 10:** Flash klipper<br/>
```bash
python3 ~/katapult/scripts/flashtool.py -i can0 -f ~/klipper/out/klipper.bin -u youruuid
```
**Flashing the remaining boards:** <br/>

Repeat step 2 (connect via USB),3 (set in DFU mode),4 (lsusb to confirm DFU),6 (flash katapult),8 (install the board),9 (pick the UUID),10 (flash klipper) for each subsequent board. Please note that as the boards are the same you do not need to re-run the menu config and make process.

> [!IMPORTANT]
> Remember to note down the UUID - Lane values for your reference. This combination will be used later to set up Happy Hare.

---

← [Step 2: Printing, Assembly and Wiring](/docs/assembly_wiring) | [Step 4: Software Setup →](/docs/software_setup/02-software-setup.md)

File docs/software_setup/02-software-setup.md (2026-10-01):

# Software Setup

The EMU needs MMU control software running alongside Klipper. Both of the options below support the EMU natively. The EMU was developed on Happy Hare and it's the software we have the most experience with. However, AFC is equally an option if you prefer it or already use it, with its setup covered in the AFC documentation.

- **[Happy Hare v4](#happy-hare-v4):** Set up with the Happy Hare `menuconfig` installer. The EMU-specific notes are below.
- **[AFC (AFC-Klipper-Add-On)](#afc-afc-klipper-add-on):** Set up with the AFC installer, following the AFC documentation.

## Table of Contents

- [Happy Hare v4](#happy-hare-v4)
  - [EMU notes for the v4 installer](#emu-notes-for-the-v4-installer)
  - [After installing](#after-installing)
- [AFC (AFC-Klipper-Add-On)](#afc-afc-klipper-add-on)

## Happy Hare v4

The EMU is supported natively in **Happy Hare v4**. Select **EMU** in the new `menuconfig` installer and it sets up the EMU defaults for you: per-lane MCUs, SLB or EBB pin mappings, LEDs, eject buttons, environment sensors, fans, the EMU Sync (PSF) buffer and the recommended speeds. You no longer need to hand-edit `mmu.cfg`, `mmu_hardware.cfg` or `mmu_parameters.cfg`.

The step-by-step installation guide is maintained in the Happy Hare documentation:

**➡️ [Getting Started with EMU – Happy Hare v4](https://moggieuk.github.io/Happy-Hare-Doc/GettingStarted-EMU/)**

> [!NOTE]
> **Still running Happy Hare v3?** The previous v3 setup guide is kept in the [legacy v3 archive](/docs/software_setup/legacy_hhv3/02-happy-hare-setup.md). The v3 instructions and config snippets don't apply to v4. If you're moving from v3 to v4, read the Happy Hare [Upgrading from v3 to v4](https://moggieuk.github.io/Happy-Hare-Doc/Upgrade-v3-v4/) guide first.

### EMU notes for the v4 installer

Keep these in mind as you work through the Happy Hare guide:

1. **Run the installer with `-e`.** `./install.sh -e` enables per-lane MCU support, which the EMU needs (each lane has its own board).
2. **MMU Type: EMU.** Set **Number of gates** to your lane count.
3. **EMU Sync version.**
   - **EMU Sync PSF (proportional):** Leave **PSF buffer** selected. This is the default and recommended option.
   - **EMU Sync with dual switches:** Deselect **PSF buffer**. The compression and tension switches are then enabled instead.
4. **Board type.** **SLB** (Solo Lane Board) is pre-selected. If you built your EMU with EBB36/42 boards, select **EBB36/42 gen1 MCU** instead.
5. **MCU connection.** Enter the `canbus_uuid` for each lane. These are the UUID-to-lane values you noted in [Step 3: EMU Board Setup](/docs/software_setup/01-board-setup.md). Lane 0 is gate 0, lane 1 is gate 1, and so on.
6. **MMU Features / Additions.** Enable or disable the environment sensors, managed fans and eject buttons to match what's fitted on your lanes. Then review each **Gate N config** menu.
7. **Toolhead.** If your extruder/hotend combination is in the **Toolhead** list, select it for community-measured starting values. If it isn't, see [Step 5: Calibration and Startup](/docs/software_setup/03-calibration-and-startup.md#toolhead-dimensions).
8. **Extruder homing method.** Happy Hare needs a sensor to detect when the filament reaches the extruder. It uses this when loading, and bowden auto-calibration depends on it. Set it in **Endstops and Bowden movement → Extruder endstop method** (`extruder_homing_endstop`):

   | Your setup | Extruder endstop method | `extruder_homing_endstop` |
   |---|---|---|
   | EMU Sync PSF (proportional), no extruder or toolhead sensor | Filament compression | `filament_compression` |
   | EMU Sync with dual switches, no extruder or toolhead sensor | Filament compression | `filament_compression` |
   | Toolhead with an extruder entry sensor (any EMU Sync version) | Extruder entry sensor + advance | `extruder` |

   - **PSF, no extruder or toolhead sensor:** Happy Hare v4 uses the PSF as a virtual compression switch, so choose `filament_compression`. This replaces the `proportional` setting used with v3. It's the default when the PSF buffer option is selected.
   - **Dual-switch EMU Sync, no extruder or toolhead sensor:** The installer may not pick `filament_compression` for you. Check this setting and select **Filament compression** if needed.
   - **Toolhead with an extruder entry sensor:** Enable the sensor under **Toolhead sensors/settings** first. You can then choose either the entry sensor or filament compression. Both work well.
   - **Toolhead with a toolhead sensor** (after the extruder gears): The extruder endstop method is only shown when **Force extruder homing** is enabled.

   Don't leave this set to `none`, or bowden auto-calibration won't work.
9. **Toolhead cutter (highly recommended).** A toolhead filament cutter, such as the [Crossbow Filament Cutter](https://github.com/DW-Tas/Crossbow-Filament-Cutter), gives cleaner and more reliable filament swaps than tip forming. The EMU [slicer setup](/docs/software_setup/05-slicer-setup.md) assumes you have one. To set it up in `menuconfig`:
   - **Toolhead sensors/settings → Has toolhead cutter?:** Enable it.
   - **Tip Forming / Cutting → Select standalone tip shaping option:** Choose **Tip cutting using toolhead cutter**. Leave **Happy Hare controlled in-print tip forming/cutting** enabled, and turn off tip forming in your slicer.
   - **Macro Variables → Toolhead tip cutting (`_MMU_CUT_TIP`):** Set the cutter geometry for your printer. At a minimum, set **Pin location (X,Y)**, **Compressed pin location (X,Y)**, **Cutting axis**, **Blade position** and **Retract length**. The pin locations depend on your printer, so measure your own rather than copying them from another build.

   See the Happy Hare [Toolhead Cutting](https://moggieuk.github.io/Happy-Hare-Doc/Macro-Toolhead-Tip-Cutting/) guide for every setting. See [Toolhead dimensions](/docs/software_setup/03-calibration-and-startup.md#toolhead-dimensions) for how to measure the blade position and retract length. Once it's configured, test the cutter as described in [First start up](/docs/software_setup/03-calibration-and-startup.md#first-start-up).
10. **Speeds.** The EMU defaults (250 mm/s bowden moves, 80 mm/s short moves, 16 mm/s extruder moves) are the same conservative values validated on the EMU with Happy Hare v3. Start with these, and only raise them once the unit is running reliably.
11. **Changing settings later.** Run `./install.sh -i` from the `Happy-Hare` folder to re-open `menuconfig`. Make changes there rather than editing the generated `.cfg` files. This keeps them from being overwritten on the next install.

### After installing

1. Complete the **Validating Hardware Setup** section of the [Happy Hare EMU guide](https://moggieuk.github.io/Happy-Hare-Doc/GettingStarted-EMU/#validating-hardware-setup). This covers gear direction, sensors, the sync-feedback buffer and LEDs.
2. Continue with [Step 5: Calibration and Startup](/docs/software_setup/03-calibration-and-startup.md) for the EMU first start up checks and calibration.
3. Then set up your slicer with [Step 6: Slicer Setup](/docs/software_setup/05-slicer-setup.md).

For anything else, the [Happy Hare v4 documentation](https://moggieuk.github.io/Happy-Hare-Doc/) covers every feature in detail, including [Sync-Feedback Buffer](https://moggieuk.github.io/Happy-Hare-Doc/Feature-Sync-Feedback-Buffer/), [FlowGuard](https://moggieuk.github.io/Happy-Hare-Doc/Feature-FlowGuard/), [Environment Manager](https://moggieuk.github.io/Happy-Hare-Doc/Feature-Environment-Manager/) and [Eject Buttons](https://moggieuk.github.io/Happy-Hare-Doc/Feature-Eject-Buttons/).

## AFC (AFC-Klipper-Add-On)

AFC also supports the EMU natively. In the AFC installer (`install-afc.sh`), choose **EMU** as the unit type, then set your lane count and board type (SLB or EBB). Follow the [AFC documentation](https://www.afcproject.dev/) for the full process:

- [AFC installation guide](https://www.afcproject.dev/installation/getting-started.html)
- [AFC Initial Startup & Commissioning guide](https://www.afcproject.dev/initial-startup/01-overview.html) (select the EMU tab)
- [AFC calibration guide](https://www.afcproject.dev/installation/calibration.html)
- [AFC slicer setup guide](https://www.afcproject.dev/installation/slicer-setup.html)

The [Happy Hare notes](#happy-hare-v4) above, [Step 5: Calibration and Startup](/docs/software_setup/03-calibration-and-startup.md), [Expanding the Unit](/docs/software_setup/04-expanding-the-unit.md) and the machine G-code in [Step 6: Slicer Setup](/docs/software_setup/05-slicer-setup.md) are written for Happy Hare. They don't apply to AFC.

---

← [Step 3: EMU Board Setup](/docs/software_setup/01-board-setup.md) | [Step 5: Calibration and Startup →](/docs/software_setup/03-calibration-and-startup.md)

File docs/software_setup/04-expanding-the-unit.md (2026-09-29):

# Expanding the Unit

This section covers adding lanes to an existing EMU installation running Happy Hare v4. It's meant to be read alongside the [Happy Hare EMU guide](https://moggieuk.github.io/Happy-Hare-Doc/GettingStarted-EMU/).

> [!NOTE]
> **Running Happy Hare v3?** Use the [legacy v3 Expanding the Unit guide](/docs/software_setup/legacy_hhv3/04-expanding-the-unit.md). It covers editing `mmu.cfg`, `mmu_hardware.cfg` and the other config files by hand.

## Table of Contents

- [Expanding the unit with more lanes](#expanding-the-unit-with-more-lanes)

## Expanding the unit with more lanes

With Happy Hare v4 you don't edit any config files by hand to add lanes. The installer generates the MCU, stepper, sensor, LED, eject button, environment sensor and fan sections for every lane, based on the number of gates.

Lanes on an additional EMU base are added the same way. All EMU lanes stay part of the same Happy Hare unit.

**Step 1: Build and flash the new lanes.** Assemble and wire the new lanes. Then flash their boards as described in [Step 3: EMU Board Setup](/docs/software_setup/01-board-setup.md). Note down each new board's `canbus_uuid` and which lane it belongs to.

**Step 2: Re-run the installer.** From your `Happy-Hare` folder, run:
```bash
cd ~/Happy-Hare
./install.sh -i
```
You don't need the `-e` flag again. The installer remembers that per-lane MCU support is enabled.

**Step 3: Update the configuration in `menuconfig`.**

1. **MMU Type → Number of gates:** Set this to your new total lane count.
2. **MCU connection:** Enter the `canbus_uuid` for each new lane. Existing lanes keep their UUIDs.
3. **MMU Features / Additions → Gate N config:** Check each new gate's environment sensor, managed fan and other per-lane options match what's fitted.

Save and exit. The installer regenerates your config files. Restart Klipper if it doesn't restart automatically.

**Step 4: Check the new lanes are visible.** Run `MMU_STATUS` and `MMU_SENSORS` and check that the new gates and their `mmu_entry_N` / `mmu_exit_N` sensors are listed. If Klipper fails to start, check the new `canbus_uuid` values.

**Step 5: Validate and calibrate the new lanes.**

1. Run the [First start up](/docs/software_setup/03-calibration-and-startup.md#first-start-up) checks for each new lane: sensors, gear direction, eject button and LEDs. If a new lane runs backwards, add a `!` to its **Gear dir pin** in `menuconfig`.
2. Bowden length is auto-calibrated the first time each new lane is loaded. To get this done before your next print, load each new lane once with its Tx command. See [Bowden length auto-calibration](/docs/software_setup/03-calibration-and-startup.md#bowden-length-auto-calibration).
3. Optionally, run the [manual rotation distance and bowden calibrations](/docs/software_setup/03-calibration-and-startup.md#manual-unit-calibration-optional---if-not-satisfied-with-automated-calibrations) for the new lanes.

If you're also adding lanes in your slicer, remember to add a filament/extruder for each new lane. See [Step 6: Slicer Setup](/docs/software_setup/05-slicer-setup.md).

---

← [Documentation Hub](/docs)

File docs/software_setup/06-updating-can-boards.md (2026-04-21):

# Updating the EMU CANBus Boards using UKAM

UKAM (Update Klipper And MCUs) automates Klipper & Kalico firmware updates for your EMU's CAN bus boards so you don't have to manually run `make menuconfig`, `make`, and `flashtool.py` each time and for every lane.

> **Prerequisite:** Your EBB boards must already have Katapult flashed per the [EMU board setup guide](/docs/software_setup/01-board-setup.md). You will need the CAN bus UUID for each board as defined in your `mmu.cfg` file.

---

## Step 1 — Install UKAM

```bash
cd ~
git clone https://github.com/fbeauKmi/update_klipper_and_mcus.git ukam
```

## Step 2 — Download and set up the menuconfig templates

UKAM needs a menuconfig config file **for each board**, and the filename must match the section name in your `mcus.ini` (e.g. `config.emu_0`, `config.emu_1`, etc.).

First, create the config directory and download the correct template for your board type:

**For EBB36/42 boards** (CAN on PB0/PB1):
```bash
mkdir -p ~/printer_data/config/ukam/config
wget -O ~/printer_data/config/ukam/config/config.emu_0 https://raw.githubusercontent.com/DW-Tas/EMU/main/macros/ukam_menuconfig_templates/config.ebb36_42
wget -O ~/printer_data/config/ukam/config/config.emu_1 https://raw.githubusercontent.com/DW-Tas/EMU/main/macros/ukam_menuconfig_templates/config.ebb36_42
# Repeat for each EBB36 board (emu_2, emu_3, etc.)
```

**For SLB boards** (CAN on PB8/PB9):
```bash
wget -O ~/printer_data/config/ukam/config/config.emu_8 https://raw.githubusercontent.com/DW-Tas/EMU/main/macros/ukam_menuconfig_templates/config.slb
wget -O ~/printer_data/config/ukam/config/config.emu_9 https://raw.githubusercontent.com/DW-Tas/EMU/main/macros/ukam_menuconfig_templates/config.slb
# Repeat for each SLB board (emu_10, emu_11, etc.)
```

> [!IMPORTANT]
> Each board **must have its own copy** of the config file. **The filename must match the section name** in `mcus.ini` — so `[emu_0]` needs `config.emu_0`, `[emu_1]` needs `config.emu_1`, and so on for all your boards.

## Step 3 — Create your `mcus.ini`

```bash
nano ~/printer_data/config/ukam/mcus.ini
```
Save and exit. 

Open the mcus.ini in mainsail/fluidd, and add a section for **each EMU board**. The section name (e.g. `[emu_0]`) must match the menuconfig filename you created in Step 2 (e.g. `config.emu_0`). The `klipper_section` must match the MCU name in your Klipper config exactly (case-sensitive).

```ini
[emu_0]
klipper_section: mcu emu_0
action_command: ~/klippy-env/bin/python3 ~/katapult/scripts/flashtool.py -i can0 -u <UUID_FOR_EMU_0>

[emu_1]
klipper_section: mcu emu_1
action_command: ~/klippy-env/bin/python3 ~/katapult/scripts/flashtool.py -i can0 -u <UUID_FOR_EMU_1>

# Repeat for each additional board...
```

Replace each `<UUID_FOR_...>` with the actual CAN bus UUIDs you noted during initial setup.

---

## Full worked example

Below is a complete `mcus.ini` for a 13-board EMU setup: 8x EBB36/42 boards (`emu_0`–`emu_7`) and 5x SLB boards (`emu_8`–`emu_12`). Each board has a matching `config.emu_X` menuconfig file in `~/printer_data/config/ukam/config/` downloaded in Step 2.

```ini
# EBB36/42 boards
[emu_0]
klipper_section: mcu mmu0
action_command: ~/klippy-env/bin/python3 ~/katapult/scripts/flashtool.py -i can0 -u cc8f39d714ce

[emu_1]
klipper_section: mcu mmu1
action_command: ~/klippy-env/bin/python3 ~/katapult/scripts/flashtool.py -i can0 -u c2357f5873d7

[emu_2]
klipper_section: mcu mmu2
action_command: ~/klippy-env/bin/python3 ~/katapult/scripts/flashtool.py -i can0 -u 31fb8c95fbfd

[emu_3]
klipper_section: mcu mmu3
action_command: ~/klippy-env/bin/python3 ~/katapult/scripts/flashtool.py -i can0 -u 8579c5130649

[emu_4]
klipper_section: mcu mmu4
action_command: ~/klippy-env/bin/python3 ~/katapult/scripts/flashtool.py -i can0 -u 7d42f7c43687

[emu_5]
klipper_section: mcu mmu5
action_command: ~/klippy-env/bin/python3 ~/katapult/scripts/flashtool.py -i can0 -u 3efbe46e5d5f

[emu_6]
klipper_section: mcu mmu6
action_command: ~/klippy-env/bin/python3 ~/katapult/scripts/flashtool.py -i can0 -u f050daaa5448

[emu_7]
klipper_section: mcu mmu7
action_command: ~/klippy-env/bin/python3 ~/katapult/scripts/flashtool.py -i can0 -u 49abda4839e6

# SLB boards
[emu_8]
klipper_section: mcu mmu8
action_command: ~/klippy-env/bin/python3 ~/katapult/scripts/flashtool.py -i can0 -u 2b62794dd839

[emu_9]
klipper_section: mcu mmu9
action_command: ~/klippy-env/bin/python3 ~/katapult/scripts/flashtool.py -i can0 -u 74d5b2c5d1ca

[emu_10]
klipper_section: mcu mmu10
action_command: ~/klippy-env/bin/python3 ~/katapult/scripts/flashtool.py -i can0 -u 8f4f90d95a7f

[emu_11]
klipper_section: mcu mmu11
action_command: ~/klippy-env/bin/python3 ~/katapult/scripts/flashtool.py -i can0 -u e78e90e44d82

[emu_12]
klipper_section: mcu mmu12
action_command: ~/klippy-env/bin/python3 ~/katapult/scripts/flashtool.py -i can0 -u 134943460803
```

## Step 4 — Add Moonraker integration (optional)

Add this to your `moonraker.conf` so UKAM appears in your web UI's update manager:

```ini
[update_manager update_klipper_and_mcus]
type: git_repo
primary_branch: main
path: ~/ukam
origin: https://github.com/fbeauKmi/update_klipper_and_mcus.git
is_system_service: False
```

## Step 5 — Update your boards

From now on, updating Klipper and all EMU boards is a single command:

```bash
~/ukam/ukam.sh -f
```

UKAM will compile firmware for your current Klipper/Kalico installed version, and flash each board via Katapult over CAN bus. It skips boards whose firmware is already current.

---

## Useful flags

| Flag | What it does |
|---|---|
| `-c` | Check-only — see if an update is available without applying it |
| `-f` | Firmware flash only, skip Klipper repo update |
| `-m` | Show menuconfig before building for all MCUs |
| `-q` | Quiet mode — fully automated, no prompts |
| `-r` | Rollback to a previous klipper/kalico version |
| `-v` | Verbose — debug output showing parsed config |

---

← [Step 6: Slicer Setup](/docs/software_setup/05-slicer-setup.md) | [Documentation Hub →](/docs)

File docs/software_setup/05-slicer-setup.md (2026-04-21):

# Slicer Setup and Optimisation for Multi Color Prints

Orca slicer is the recommended slicer for the EMU. This section will take you through a set of mandatory and recommended settings to help you achieve the best results possible from your EMU. It assumes that you are using a toolhead equipped with a cutter. Therefore all tip forming activity in the slicer will be disabled.

<p align="center">
  1 (4)
  1 (5)
  1 (2)
  1 (3)
</p>

## Table of Contents

- [Orca slicer mandatory setup](#orca-slicer-mandatory-setup)
  - [Machine G-Code setup](#machine-g-code-setup)
    - [Machine Start G-code](#machine-start-g-code)
    - [Machine End G-code](#machine-end-g-code)
    - [Layer change G-code](#layer-change-g-code)
    - [Change Filament G-code](#change-filament-g-code)
  - [Multi Material setup](#multi-material-setup)
  - [Extruder setup](#extruder-setup)
  - [Filament selection](#filament-selection)
- [Orca slicer profile tuning for multi-color printing](#orca-slicer-profile-tuning-for-multi-color-printing)
  - [Reducing color bleed](#reducing-color-bleed)
    - [Maximise the time spent printing hidden features before moving to the outer wall](#maximise-the-time-spent-printing-hidden-features-before-moving-to-the-outer-wall)
    - [Disable flush into objects' infill and support](#disable-flush-into-objects-infill-and-support)
    - [Use 3 (or more) walls](#use-3-or-more-walls)
    - [Use the blobifier](#use-the-blobifier)
    - [Tune your purge multiplier](#tune-your-purge-multiplier)
    - [Increase your variable_retract_length (mmu_macro_vars.cfg)](#increase-your-variable_retract_length-mmu_macro_varscfg)
  - [Optimising Print Quality](#optimising-print-quality)
    - [Speed settings](#speed-settings)
    - [Quality settings](#quality-settings)

## Orca slicer mandatory setup

### Machine G-Code setup
#### Machine Start G-code:
The Orca Slicer print start gcode is required to be amended to include the below additions. 
```
MMU_START_SETUP INITIAL_TOOL={initial_tool} TOTAL_TOOLCHANGES=!total_toolchanges! REFERENCED_TOOLS=!referenced_tools! TOOL_COLORS=!colors! TOOL_TEMPS=!temperatures! TOOL_MATERIALS=!materials! FILAMENT_NAMES=!filament_names! PURGE_VOLUMES=!purge_volumes!
MMU_START_CHECK
PRINT_START HOTEND=[nozzle_temperature_initial_layer] BED=[bed_temperature_initial_layer_single] CHAMBER=[chamber_temperature]
MMU_START_LOAD_INITIAL_TOOL
SET_PRINT_STATS_INFO TOTAL_LAYER={total_layer_count} ; For pause at layer functionality and better print stats
```
> [!WARNING]
> Replace the print start line with your existing print start command!

#### Machine End G-code:
The Orca Slicer print end gcode is required to be amended to include the below additions. 
```
MMU_END
PRINT_END ; your existing print end macro
```
> [!WARNING]
> Replace the print end line with your existing print end command!

#### Layer change G-code
**After Layer change:**</br>
```
; ... your existing layer change G-code...
SET_PRINT_STATS_INFO CURRENT_LAYER={layer_num + 1}
_MMU_UPDATE_HEIGHT
```

#### Change Filament G-code
If using a purge block set up:
```
T[next_extruder]
```
If you have the blobifier add-on set up, add the below change filament g-code. This will enable purge volume reporting in the slicer. Also the retraction command is necessary to avoid double de-retracting and oozing on the prime tower.
```
T[next_extruder]
G1 E-{new_retract_length} F3000
; FLUSH_START
; EXTERNAL_PURGE {flush_length}
; FLUSH_END
```

### Multi Material setup
Ensure that in the Multi Material tab, the below settings are set up:
1. Single Extruder Multi Material = selected
2. Extruders = 1
3. Manual Filament Change = de-selected
4. Purge in prime tower = selected. Deselect only if using the blobifier or similar purging system
5. Enable filament ramming = de-selected
6. Single extruder multi-material parameters - all set to 0 and high extruder current on filament swap = de-selected
7. Set up the advanced section with the approximate filament swap times - you can get these by typing MMU_STATS in the printer console after you have successfully ran a few multi-color prints

**No blobifier:**
<p align="center">
  
</p>

**With the blobifier:**
<p align="center">
  
</p>

### Extruder setup
Ensure that in the Extruder tab, the below settings are set up:
1. Retraction when switching material = 0

<p align="center">
  
</p>

### Filament selection
Using the (+) button, add as many filaments as available lanes in your EMU. 

<p align="center">
  
</p>

## Orca slicer profile tuning for multi-color printing

### Reducing color bleed
One of the biggest downsides to multi-color printing with a single nozzle is **the potential for color bleed**. This is usually the case when:
1. When swapping from **high saturation colors (red, black) to white**
2. Combined with **too low of a purge volume**
3. And using a **long meltzone hotend**

This happens due to the **molten material sticking to the hotend melt zone** and requiring disproportional amount of filament to "disrupt" that boundary layer and flush the color through. This is made worse by the fact that **filament flows in a laminar way**, hence there is little to no "turbulence" in the hotend to disrupt that layer.. 

Ways to mitigate include:
1. Use a regular flow (not a CHT) nozzle. The extra filament channels multiply the surface area that the boundary layer can be created against
2. Use a small meltzone nozzle. For multi-color printing, the vast majority of print time is spent swapping filaments and purging. Hence a lower flow hotend will not impact overall print speed by a significant factor

In addition to the above physical changes, the **below slicer settings can help** contain the color bleed

#### Maximise the time spend printing hidden features before moving to the outer wall
1. Enable Inner Outer Inner wall ordering mode.
2. Enable print infill first.
Printing **infill first results in the printer spending more time printing inside the model** before transitioning to the visible surfaces of the model (outer wall). It, therefore, increases the amount of filament extruded before the outer walls are printed and the probability that the outer walls will not show color bleed. **Inner Outer Inner wall ordering hides the resulting artefacts** from printing infill first.

For comparison, outer inner wall ordering mode must be avoided as it will print the external facing walls first, immediately after a color change!

<p align="center">
  
</p>

#### Disable flush into objects' infill and support
Similarly to the point above, disabling these settings ensures that **your defined purge volume is spent outside the model**.

<p align="center">
  
</p>

#### Use 3 (or more) walls
As above, the more walls printed before the outer perimeter, the higher the chance that the external walls are printed without color bleed.

<p align="center">
  
</p>

#### Use the blobifier
The blobifier algorithm **executes purging with varying speeds**, which helps **disrupt the laminar flow** of the filament against the walls. If your printer can accomodate the blobifier setup, it is strongly recommended that you set it up.

<p align="center">
  
</p>

In the picture above, you can see the no color bleed transition between white and black on the same layer. In addition you can observe the "ripples" created on the purge blobs due to the blobifier varying the purge speed and retracting and de-retracting during the purge, to flush out the filament from the nozzle.

> [!NOTE]
> If you are using the blobifier **do not disable the prime tower**. The prime tower will not be used to "purge" filament, rather **re-prime the nozzle**, clear out any air bubbles in the hotend that may have occured during the purge process and equalize nozzle pressure before resuming printing on the model. <br/>
> Set the prime volume to be equal to your meltzone volume **(meltzone length in mm * 2.4)**

<p align="center">
  
</p>

#### Tune your purge multiplier
Reducing the purge multiplier to 0.8-0.7 will indeed save some purge material; however more likely than not (unless you are using a particularly small meltzone hotend) it will result in color bleed. Now depending on how clean you want your prints to look, a purge multiplier of 1.2-1.25 (or more) is not unusual.

<p align="center">
  
</p>

> [!NOTE]
> Make sure your **nozzle volume is accurately set in the slicer** settings!

<p align="center">
  
</p>

#### Increase your variable_retract_length (mmu_macro_vars.cfg)
Reducing the amount of left over filament in the hotend can help reduce slightly the amount of material needing to be purged. I**ncreasing the variable_retract_length value to be ~5-10mm less than the variable_blade_pos** is recommended. 

> [!IMPORTANT]
> Make sure you **enable variable_simple_tip_forming**. It reduces the probability of clogs at the hotend when performing large retractions!<br/>
> Also make sure your variable_pushback_length plus toolhead_ooze_reduction is a mm or two less than your variable_retract_length.<br/>
> <br/>
> If you get persistent clogging with the above mitigations enabled, reduce your variable retract length until it stops. Proportionally also reduce the push back length (even though too large values there will be ignored, however update for configuration correctness)

### Optimising Print Quality
As the vast majority of the time during multi-color printing is spent in tool swapping, you can afford to set conservative print settings which can materially improve the produced output with very little time tradeoff.

The below are my preferred settings for multi-color printing.

**Speed settings:**
<p align="center">
  1 (4)
  1 (5)
</p>

**Quality settings:**
<p align="center">
  1 (4)
  1 (5)
  1 (5)
</p>

---

← [Step 5: Calibration and Startup](/docs/software_setup/03-calibration-and-startup.md) | [Step 7: Updating CAN Boards with UKAM →](/docs/software_setup/06-updating-can-boards.md)

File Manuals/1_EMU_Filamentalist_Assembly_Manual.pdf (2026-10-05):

WWW.DWTAS.NET

# EMU Filamentalist Assembly

### EMU - The Expandable Multi-material Unit

VERSION 0.91 BETA - 2026-10-05

WHAT YOU’LL NEED | WWW.DWTAS.NET
- Flush cutters
- Soldering iron
- Solder
- Wire stripper
- Crimping tool
- 300mm Ruler
- Measuring tape
- 2mm & 2.5mm Ball End Hex key
- Countersinking tool or 4mm drill bit to chamfer the PTFE tubes
- PTFE cutter tool (optional)
- A kitchen blowtorch or heat gun (optional but highly recommended)

PART PRINTING GUIDELINES | WWW.DWTAS.NET

To have the best chance of success, the following print settings are highly recommended.

3D PRINTING PROCESS
Fused Deposition Modeling (FDM)

INFILL TYPE
Gyroid or Cubic

MATERIAL
ABS/ASA. Glass and CF filled material are not recommended

INFILL PERCENTAGE
Recommended: 40%

LAYER HEIGHT
Mandatory: 0.2mm, including first layer!

WALL COUNT
Recommended: 4
One Wall Top and Bottom surface

EXTRUSION WIDTH
0.4mm, Arachne slicing engine.
Infill can be printed wider (0.45/0.48) to increase layer bonding.

SOLID TOP/BOTTOM LAYERS
Recommended: 5

SHRINKAGE COMPENSATION
Parts are not compensated for filament shrinkage.
Calibrate your filament shrinkage compensation in the slicer before printing.

ECAS CONNECTORS PREPARATION | WWW.DWTAS.NET

Remove

CAUTION:
Whenever we are using ECAS in this manual, the seal retainer and the seal should be removed

WWW.DWTAS.NET

# CHAPTER 1: WIRING PREPARATION

PREPARE THE FILAMENTALIST SWITCH SENSORS | WWW.DWTAS.NET

Start off by preparing the wiring for the filamentalist switch sensors. Their assembled position and naming is shown below.

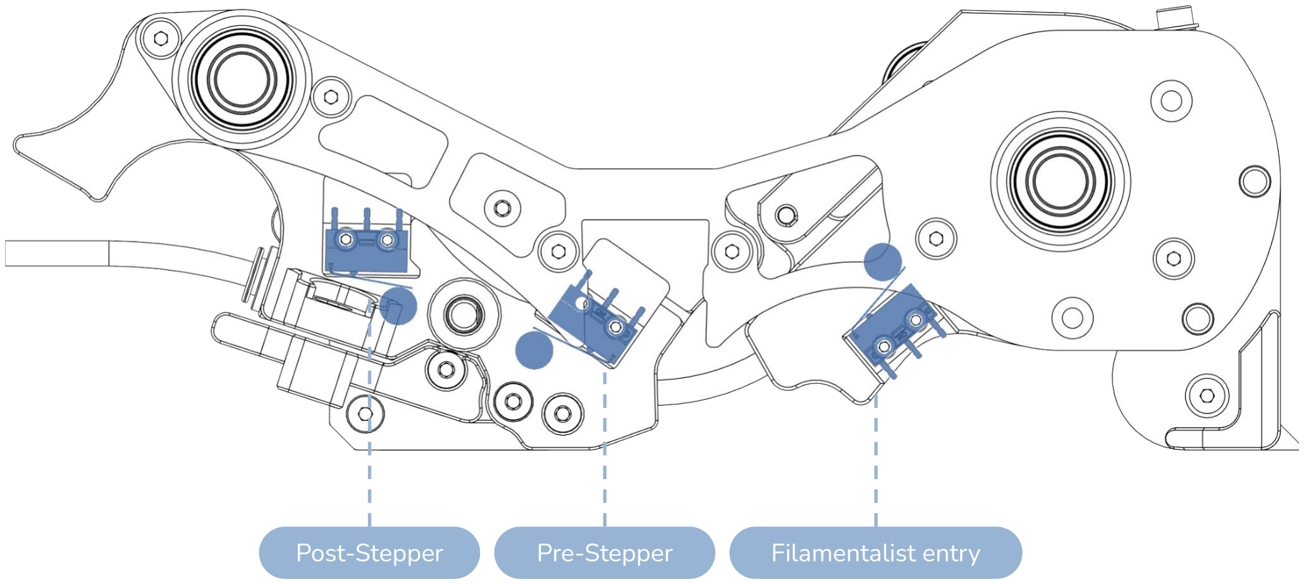
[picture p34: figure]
Post-Stepper; Pre-Stepper; Filamentalist entry

PREPARE THE FILAMENTALIST SWITCH SENSORS | WWW.DWTAS.NET
Step 2: If not pre-terminated, crimp JST XH

Depending on the source of your kit, the JST XH terminals may already be installed on the wires. Wire orientation does not affect their functionality - ie C and NC can be swapped around. Measurements are from the end of the JST plug to the end of the wire.

PREPARE THE FILAMENTALIST SWITCH SENSORS | WWW.DWTAS.NET
Step 3: Strip the insulation from the wire free end, pre-tin wires and switch legs and solder to the D2F-L switch outer two terminals as

CAUTION:
Pay attention to the switch and lever orientation!

WWW.DWTAS.NET

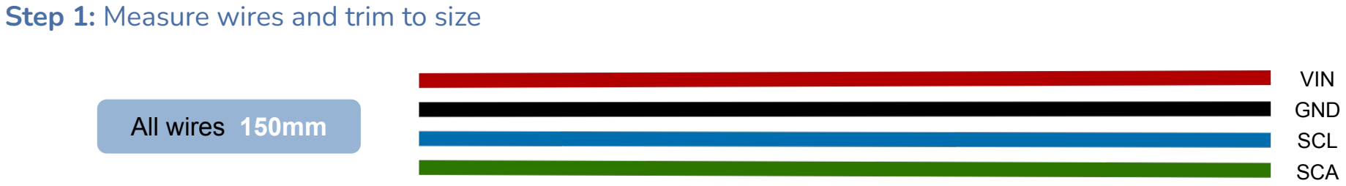
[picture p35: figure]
Step 1: Measure wires and trim to size; All wires 150mm; VIN; GND; SCL; SCA

Step 2: If not pre-terminated, crimp JST XH terminal. Insert to JST XH plug
Step 3: Strip the insulation from the wire free end, pre-tin wires and solder to the sensors as shown below.

VIN
GND
SCL
SCA

Depending on the source of your kit, the JST XH terminals may already be installed on the wires. Measurements are from the end of the JST plug to the end of the wire.

## PREPARE THE BME280 / AHT20 SENSOR

PREPARE THE NEOPIXEL | WWW.DWTAS.NET

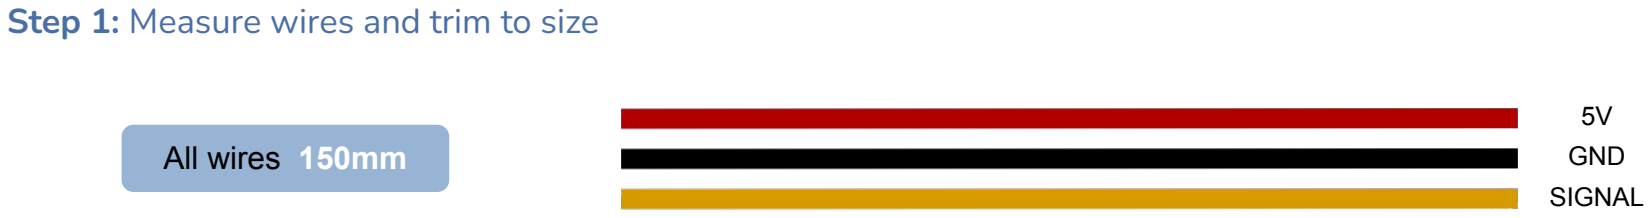
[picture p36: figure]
Step 1: Measure wires and trim to size; All wires 150mm; GND; SIGNAL

Step 2: If not pre-terminated, crimp JST XH terminal. Insert to JST XH plug
Step 3: Strip the insulation from the wire free end, pre-tin wires and solder to the sensors as shown below.

Depending on the source of your kit, the JST XH terminals may already be installed on the wires. Depending on the source of your kit, the yellow wire may be “brown” or “orange”
Measurements are from the end of the JST plug to the end of the wire.

WWW.DWTAS.NET

For the BOM steppers (OMC & Usongshine): The green and blue wires should be swapped on stepper side to match the AABB of the hatch board.
If using other steppers: refer to your stepper motor data sheet for its AABB pin output order.

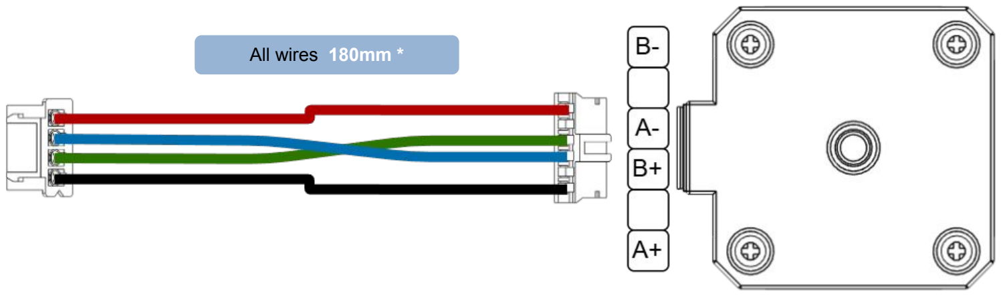
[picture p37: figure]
All wires 180mm *

Depending on the source of your kit, the JST XH terminals may already be installed on the wires.
Depending on the source of your kit, the wires may be pre-crimped at 200mm. That is perfectly fine. The 20mm difference is not important. Measurements are from the end of the JST plug to the end of the wire.

## PREPARE THE STEPPER MOTOR

CUT THE PTFE TUBES TO SIZE | WWW.DWTAS.NET

Insert a 4mm OD, 2.5mm ID piece of bowden tube in the cutting jig. Cut flush with the body using a blade. Alternatively mark with a pen and cut using a PTFE tube cutter.

Cut one of each: front (F) and rear (R) tubes.

CHAMFER THE PTFE TUBES | WWW.DWTAS.NET

Filament path

CAUTION:
To ensure smooth feeding of the filament, it is recommended that all inlet sides of the PTFE tubes are slightly chamfered. This can be done using a countersinking tool or a 4mm drill bit.

WWW.DWTAS.NET

# CHAPTER 2: FILAMENTALIST ASSEMBLY

INSERT HEATSET INSERTS | WWW.DWTAS.NET

M3 Heat Set Insert

Stepper_Main_Body.stl

EMU_Tensioner_Moun
t_with_Sensor.stl

INSERT HEATSET INSERTS | WWW.DWTAS.NET

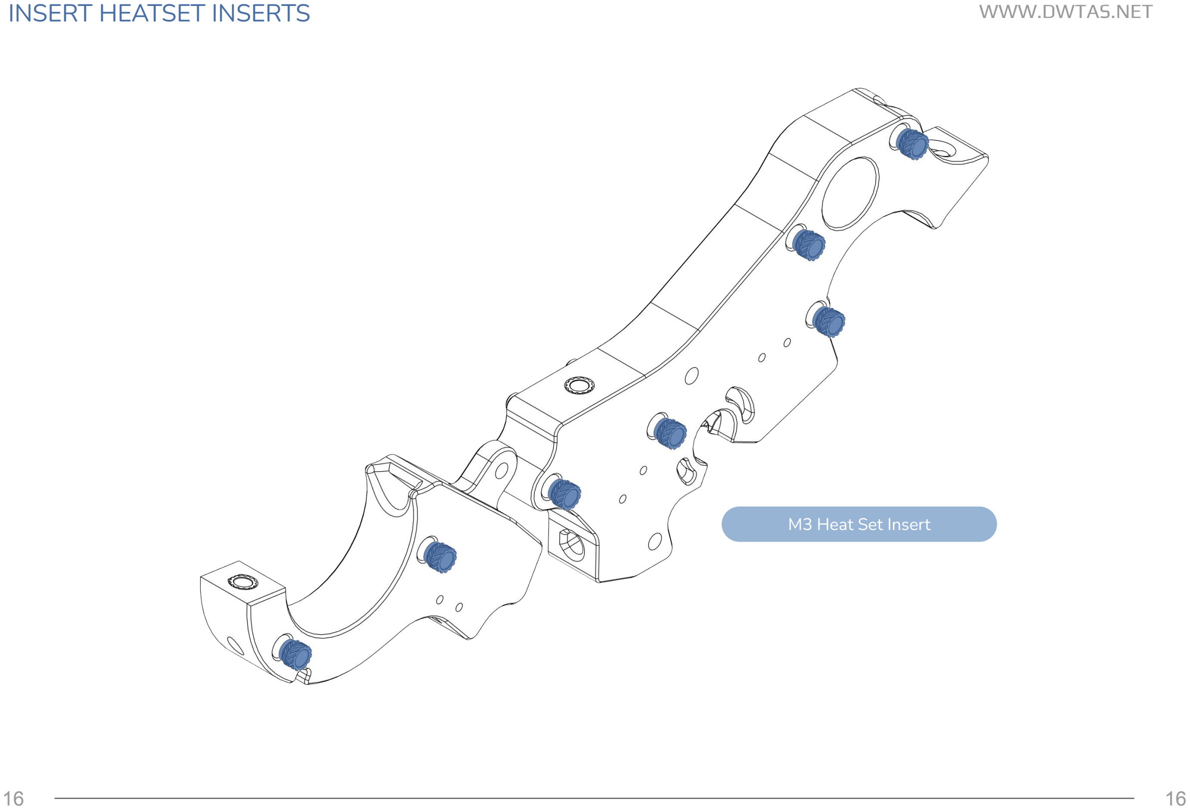
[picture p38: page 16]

M3 Heat Set Insert

INSERT HEATSET INSERTS | WWW.DWTAS.NET

INSERT HEATSET INSERTS | WWW.DWTAS.NET

CAUTION:
The insert must at inserted at an angle of 5°

CAUTION:
The insert should be
recessed by ~1mm to be
fully seated

M3 Heat Set Insert

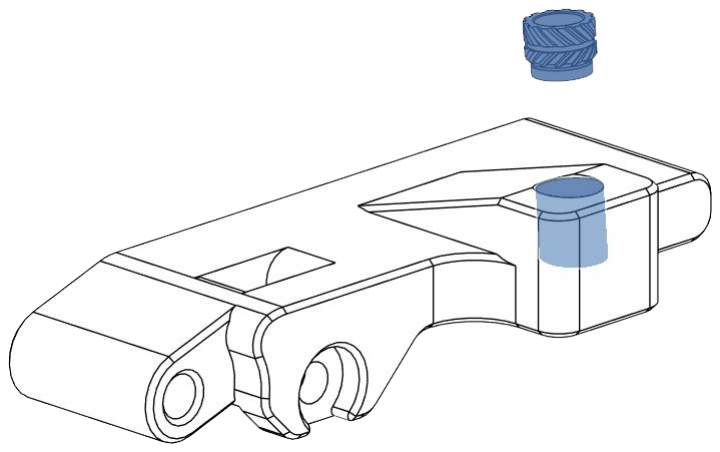
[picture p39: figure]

[a]_Stepper_Tension_Arm[MR693zz].stl

INSERT BALL BEARINGS | WWW.DWTAS.NET

Lay the bearing on a flat surface and push down the frame so it’s easier to insert straight

688 Ball bearing

Chassis_L_688_Bearing.stl

Chassis_R_688_Bearing.stl

TEST FIT ONE WAY BEARING | WWW.DWTAS.NET

Test fit the one way bearing on the axle. Ensure it spins smoothly.

If it doesn’t use a blowtorch to gently heat up the shaft, add the bearing while the shaft is hot and spin it around. This will adjust the inner locking mechanism tolerance and give a smoother rotation.

Once done, remove the one way bearing from the shaft and set aside.

8mm x 70mm Dowel Pin

INSERT ONE WAY BEARING INTO CDR | WWW.DWTAS.NET

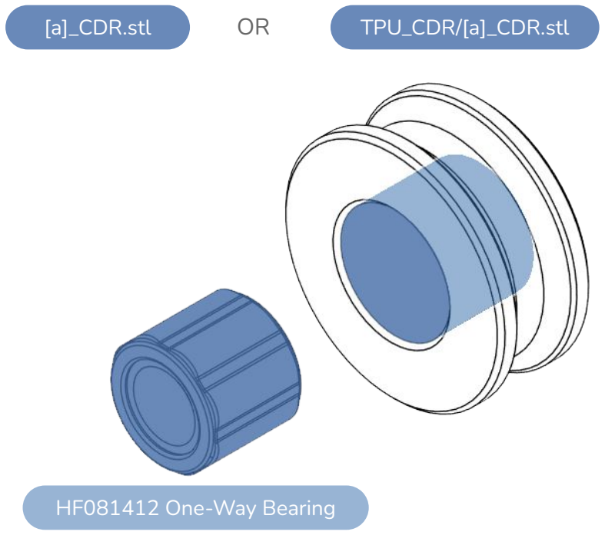
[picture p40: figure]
HF081412 One-Way Bearing; [a]_CDR.stl; TPU_CDR/[a]_CDR.stl

Lay the bearing on a flat surface and push the CDR down till flush with the surface.

ADD THE O-RINGS TO THE CDR | WWW.DWTAS.NET

22

TPU Printed | NBR O-Ring

22

[TPU]_Half_Ring_Flex_1.65mm_x2.stl

TPU_CDR/[a]_CDR.stl | [a]_CDR.stl

INSERT ECAS FITTINGS IN MAIN BODY | WWW.DWTAS.NET

Remember to remove and discard the retainer and the seal

INSERT MR85 BEARING INTO MAIN BODY | WWW.DWTAS.NET

MR85 bearing

Stepper_Main_Body.stl

CAUTION:
Make sure the bearing hole is clear of any loose bridges. Don't push too hard as you may break the plastic part! Make sure the bearing is fully seated.

ASSEMBLE THE MAIN BODY TO THE CHASSIS | WWW.DWTAS.NET

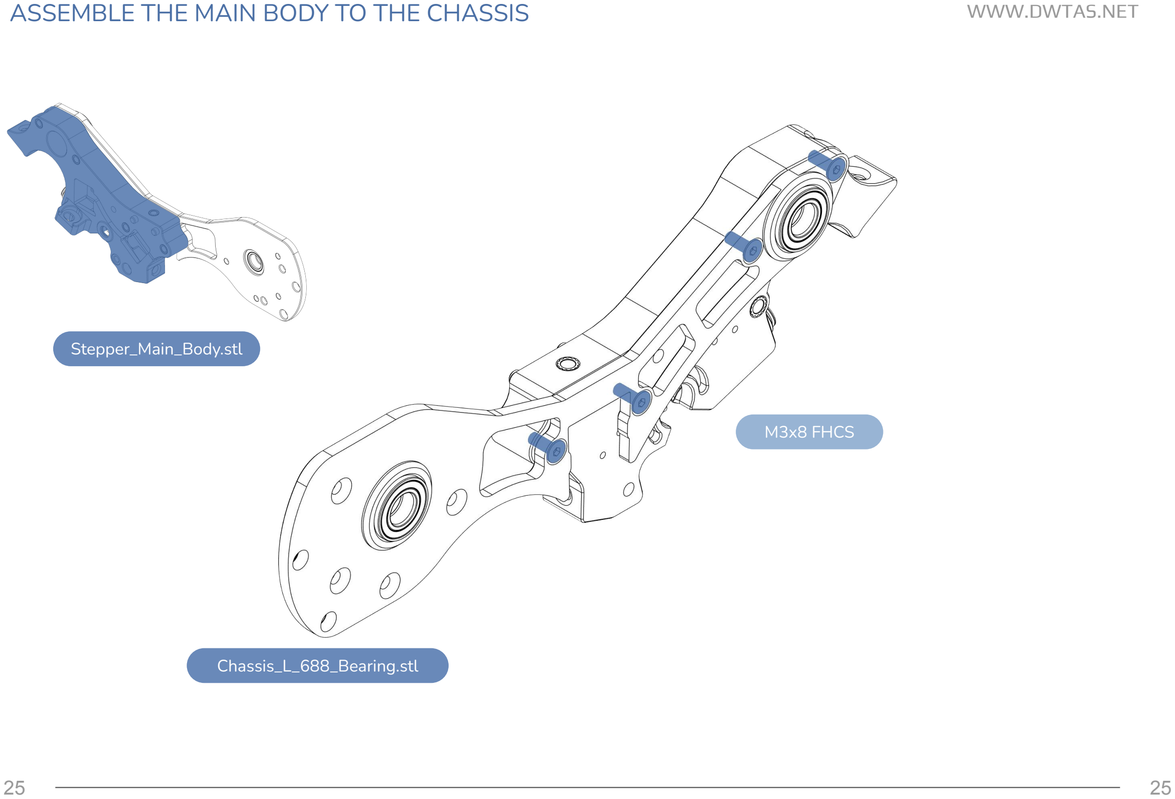
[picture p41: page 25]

Chassis_L_688_Bearing.stl

M3x8 FHCS

Stepper_Main_Body.stl

INSERT THE FRONT PTFE TUBE | WWW.DWTAS.NET

ASSEMBLE THE TENSIONER MOUNT TO THE CHASSIS | WWW.DWTAS.NET

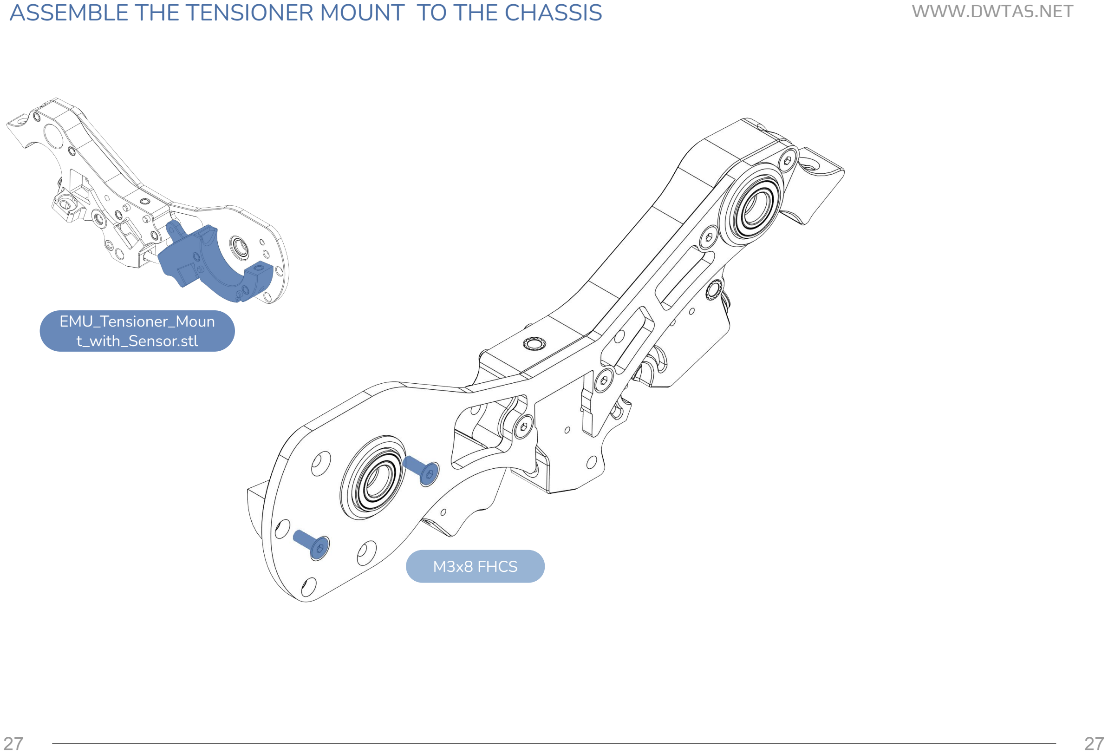
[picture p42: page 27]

M3x8 FHCS

EMU_Tensioner_Moun
t_with_Sensor.stl

ASSEMBLE THE STEPPER MOTOR PLATE | WWW.DWTAS.NET

M3 Square nut

M3x6 FHCS

M3x6 FHCS

M3x6 BHCS

[a]_Stepper_Motor_Plate.stl

M3 Square nut

180°

ASSEMBLE THE BMG GEAR & GRUB SCREW | WWW.DWTAS.NET

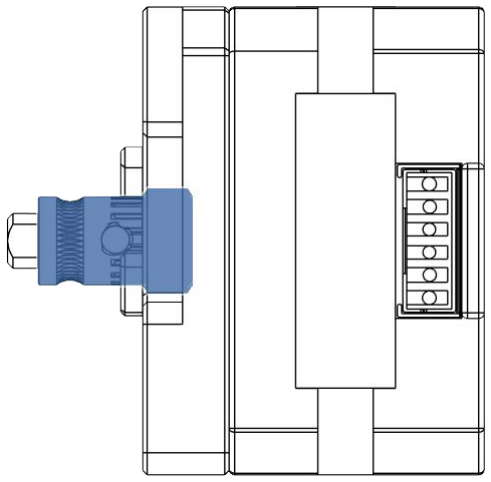
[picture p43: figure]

BMG Gear

M2 Grub screw

Tighten screw down, then unscrew by half a turn.

The BMG gear should be able to move up and down the shaft but not spin freely around the shaft.

Align the stepper
shaft flat spot
with the grub
screw

ATTACH THE STEPPER TO THE MAIN BODY | WWW.DWTAS.NET

M3x20 BHCS

ATTACH THE STEPPER TO THE MAIN BODY | WWW.DWTAS.NET

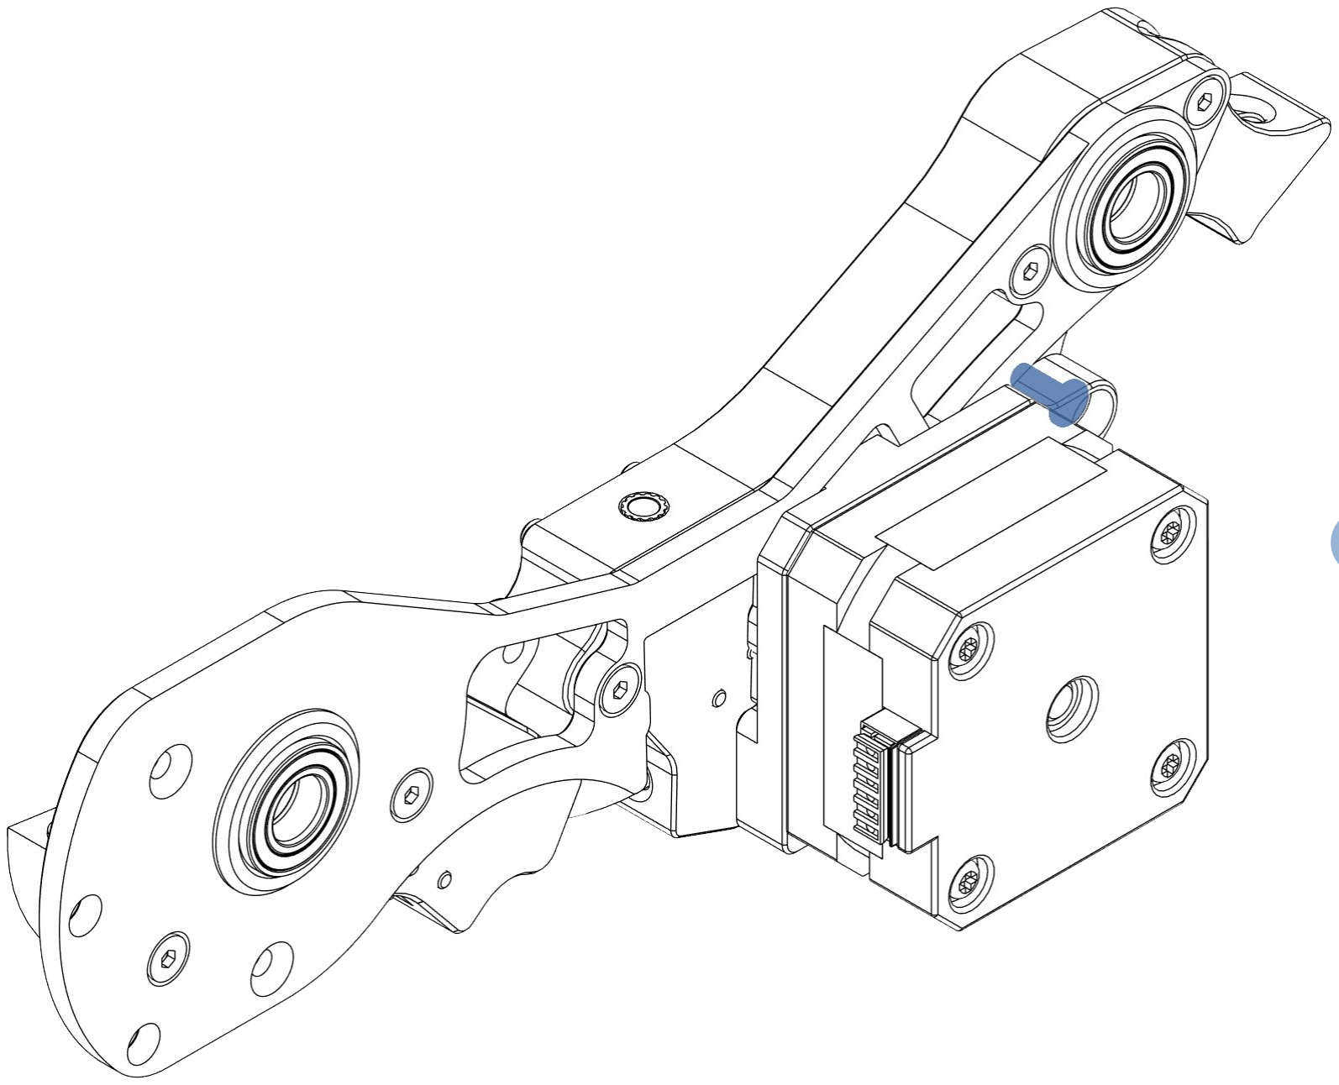
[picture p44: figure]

M3x8 FHCS

INSERT & SECURE THE TENSIONER ARM BEARING | WWW.DWTAS.NET

688 Ball bearing

688_Bearing_Bushing.stl

CAUTION:
Be careful not to strip the plastic while securing the screw. The screw needs to be “finger tight” (snug).
Back the screw out by half a turn and make sure the bearing spins freely. The bearing may wobble side to side a little. That is perfectly fine.

ATTACH THE TENSIONER ARM TO THE ASSEMBLY | WWW.DWTAS.NET

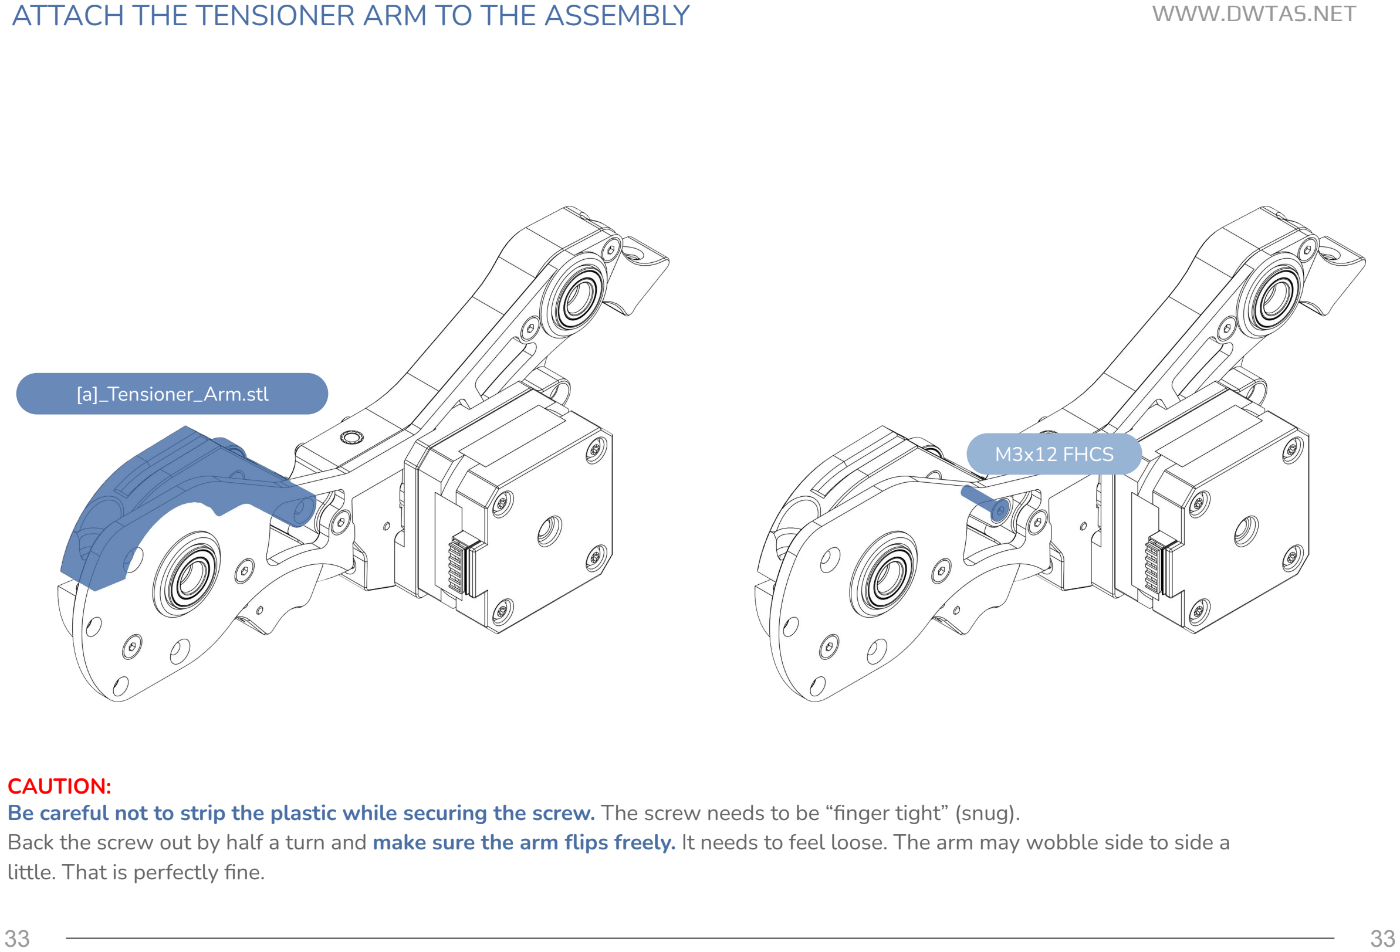
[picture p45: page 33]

M3x12 FHCS

[a]_Tensioner_Arm.stl

CAUTION:
Be careful not to strip the plastic while securing the screw. The screw needs to be “finger tight” (snug).
Back the screw out by half a turn and make sure the arm flips freely. It needs to feel loose. The arm may wobble side to side a little. That is perfectly fine.

TEST FIT THE SENSOR MAGNETS / DISKS | WWW.DWTAS.NET

CAUTION:
The magnets must be loose enough to fall out on their own when you flip the assembly over. If they are tight this can cause sensor activation issues. This is caused by either incorrect shrinkage compensation or broken bridges when printing the part. You can alternatively self source and use a set of MR63 bearings in place of the magnets/disks if they are too tight.

Depending on your kit source the magnets may need to be demagnetised. Use a blowtorch to gently heat them up till they lose their magnetism.

PLACE AND SECURE THE ENTRY SENSOR | WWW.DWTAS.NET

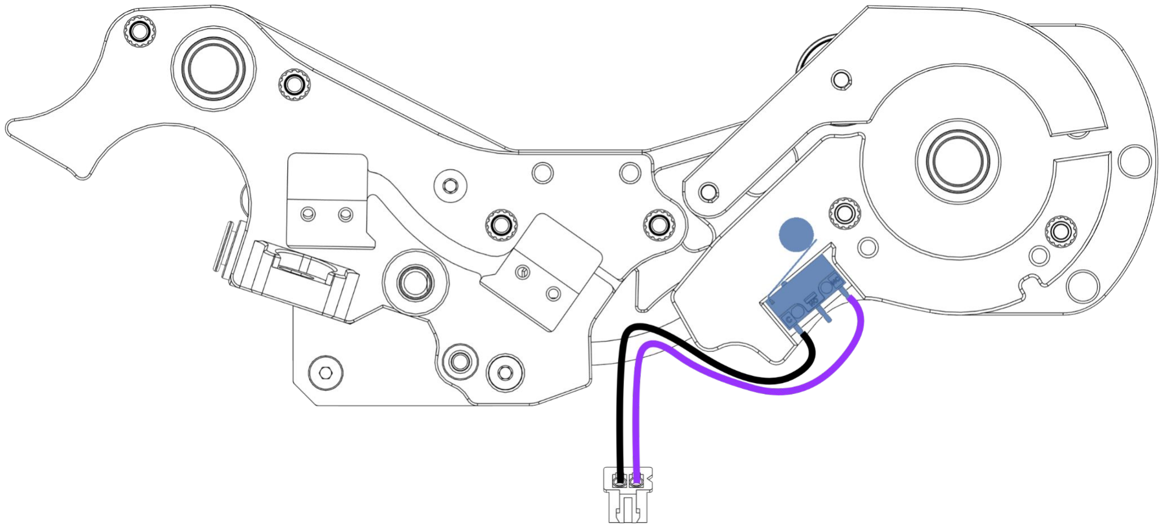
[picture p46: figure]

M2x10 Self Tapping

Install the entry sensor switch into the Filamentalist tensioner assembly.

Place the magnet/disk/bearing and align the switch as shown.

Install the two screws to secure the switch. Careful not to overtighten!

PLACE AND SECURE THE PRE-STEPPER SENSOR | WWW.DWTAS.NET

M2x10 Self Tapping

Install the pre-stepper sensor switch into the Filamentalist tensioner assembly.

Place the magnet/disk/bearing and align the switch as shown.

Install the two screws to secure the switch. Careful not to overtighten!

PLACE AND SECURE THE POST-STEPPER SENSOR | WWW.DWTAS.NET

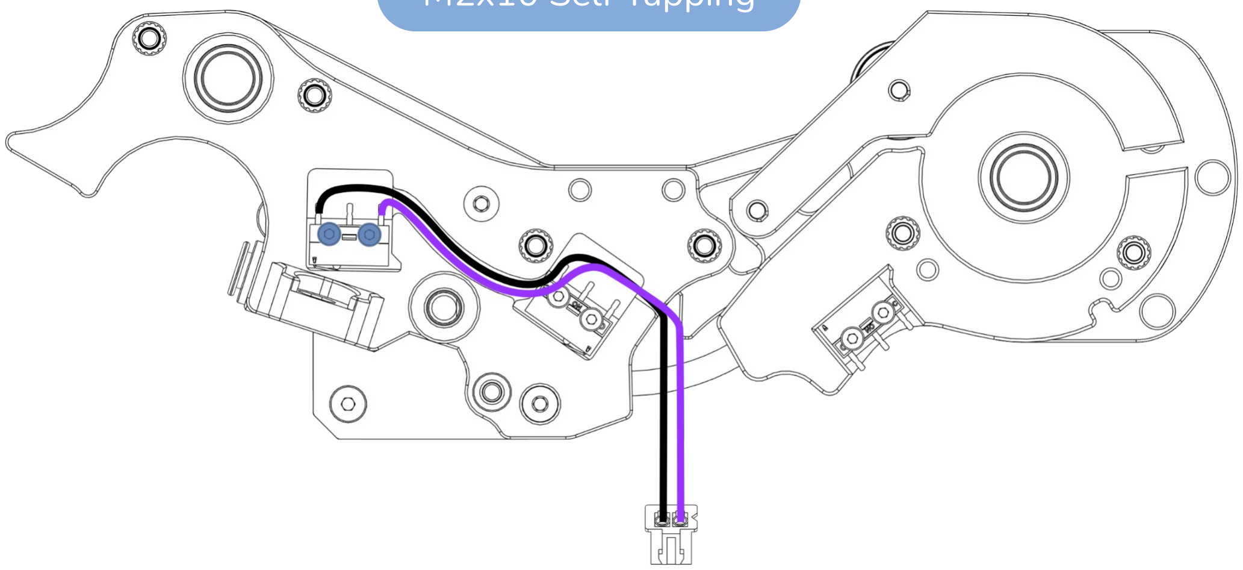
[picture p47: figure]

M2x10 Self Tapping

Install the post stepper sensor switch into the Filamentalist tensioner assembly.

Place the magnet/disk/bearing and align the switch as shown.

Install the two screws to secure the switch. Careful not to overtighten!

TEST THE SENSORS TO ENSURE THEY TRIGGER AND RELEASE | WWW.DWTAS.NET

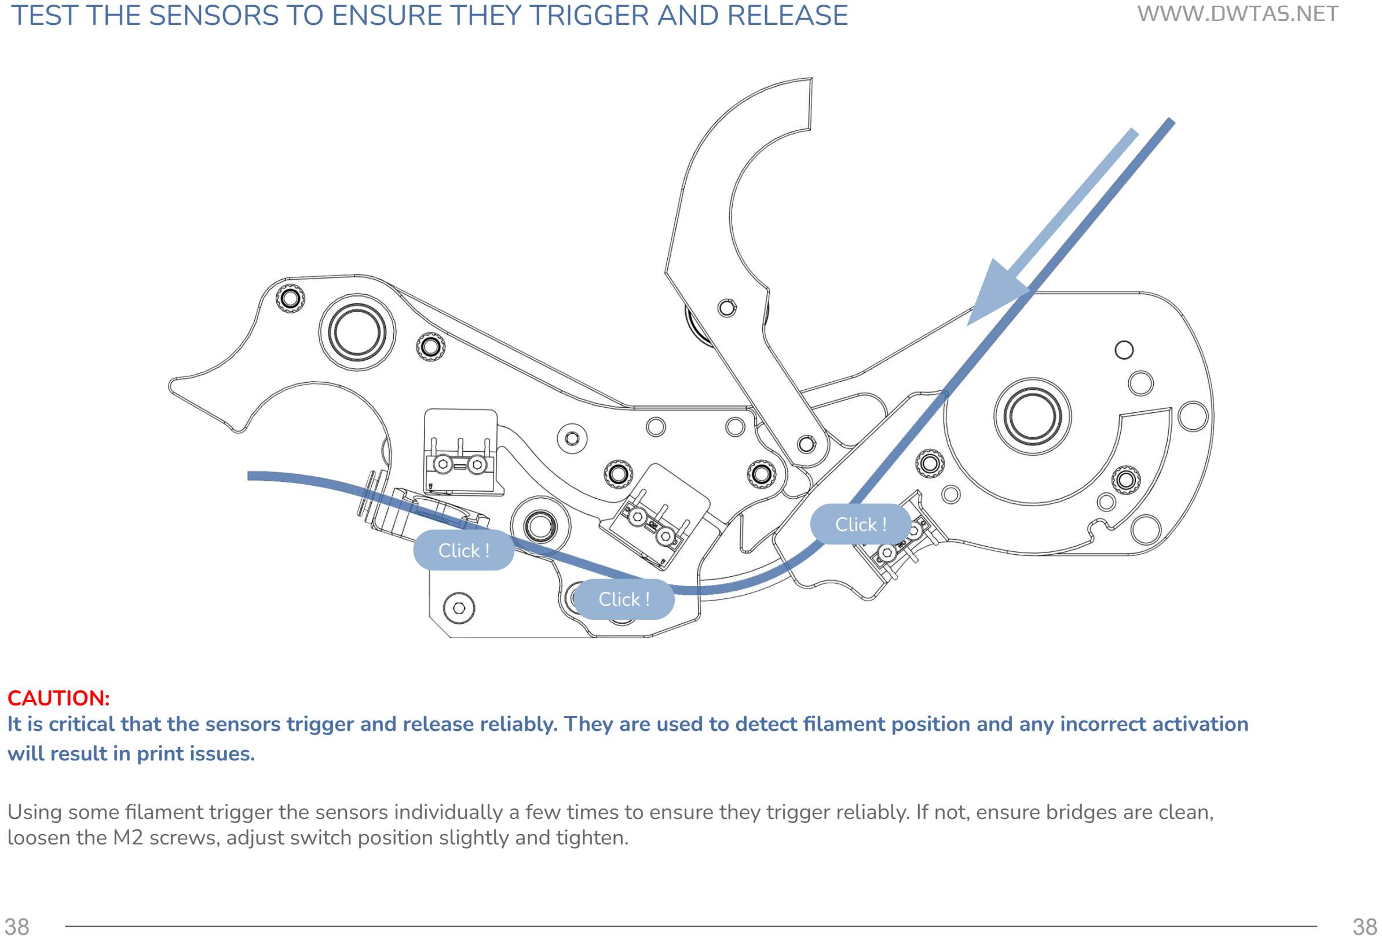
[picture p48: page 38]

Click !

Click !

Click !

CAUTION:
It is critical that the sensors trigger and release reliably. They are used to detect filament position and any incorrect activation will result in print issues.

Using some filament trigger the sensors individually a few times to ensure they trigger reliably. If not, ensure bridges are clean, loosen the M2 screws, adjust switch position slightly and tighten.

SECURE THE BOX MOUNT SIDES TOGETHER | WWW.DWTAS.NET

INSTALL THE BOX MOUNT AND IDLE ROLLER AXLE | WWW.DWTAS.NET

Idler_Roller_Axle.stl

Assembled box mount

ATTACH THE RIGHT CHASSIS SIDE TO THE ASSEMBLY | WWW.DWTAS.NET

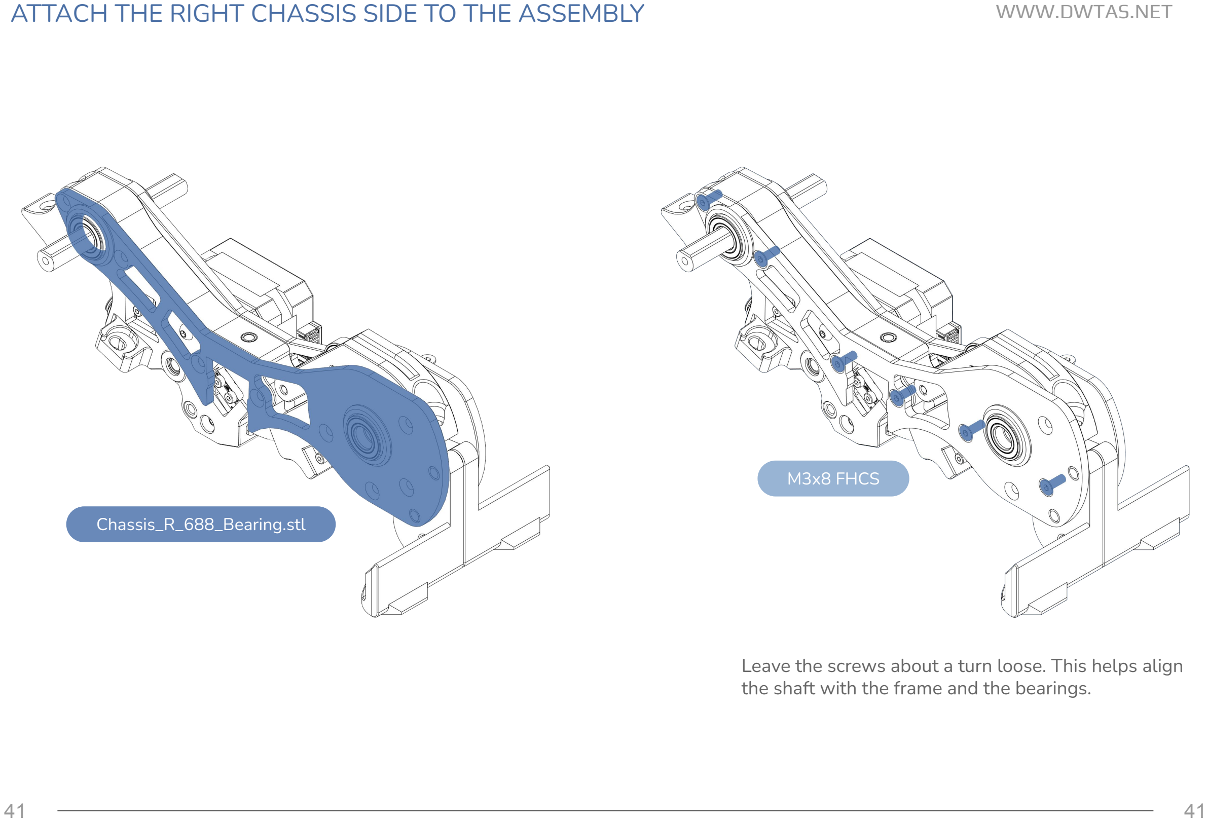
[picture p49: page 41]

Chassis_R_688_Bearing.stl

M3x8 FHCS

Leave the screws about a turn loose. This helps align the shaft with the frame and the bearings.

ADD SOME GREASE TO THE CDR ONE WAY BEARING | WWW.DWTAS.NET

Add a dab of grease to the one way bearing needle rollers and spread it around evenly.

This helps ensure the bearing spins smoothly and releases reliably.

PLACE THE CDR & INSERT AXLE | WWW.DWTAS.NET

The highlighted white plastic part should face towards the left

If the shaft is too tight against the bearings use some medium grit sandpaper to sand it down a little. It needs to be a snug fit.

Don't force it in the bearings as then you won't be able to remove the CDR for maintenance!

Tip: Use a drill or dremel to spin the shaft while you’re sanding it down with the sandpaper.

## ENSURE THE ONE WAY BEARING LOCKS & UNLOCKS IN THE RIGHT DIRECTION WWW.DWTAS.NET

While holding the axle, the CDR should unlock and move freely in the BLUE direction, ie pushing filament through the stepper. It should lock and not move in the RED arrow direction, ie. pulling filament out.

FULLY TIGHTEN THE SCREWS | WWW.DWTAS.NET

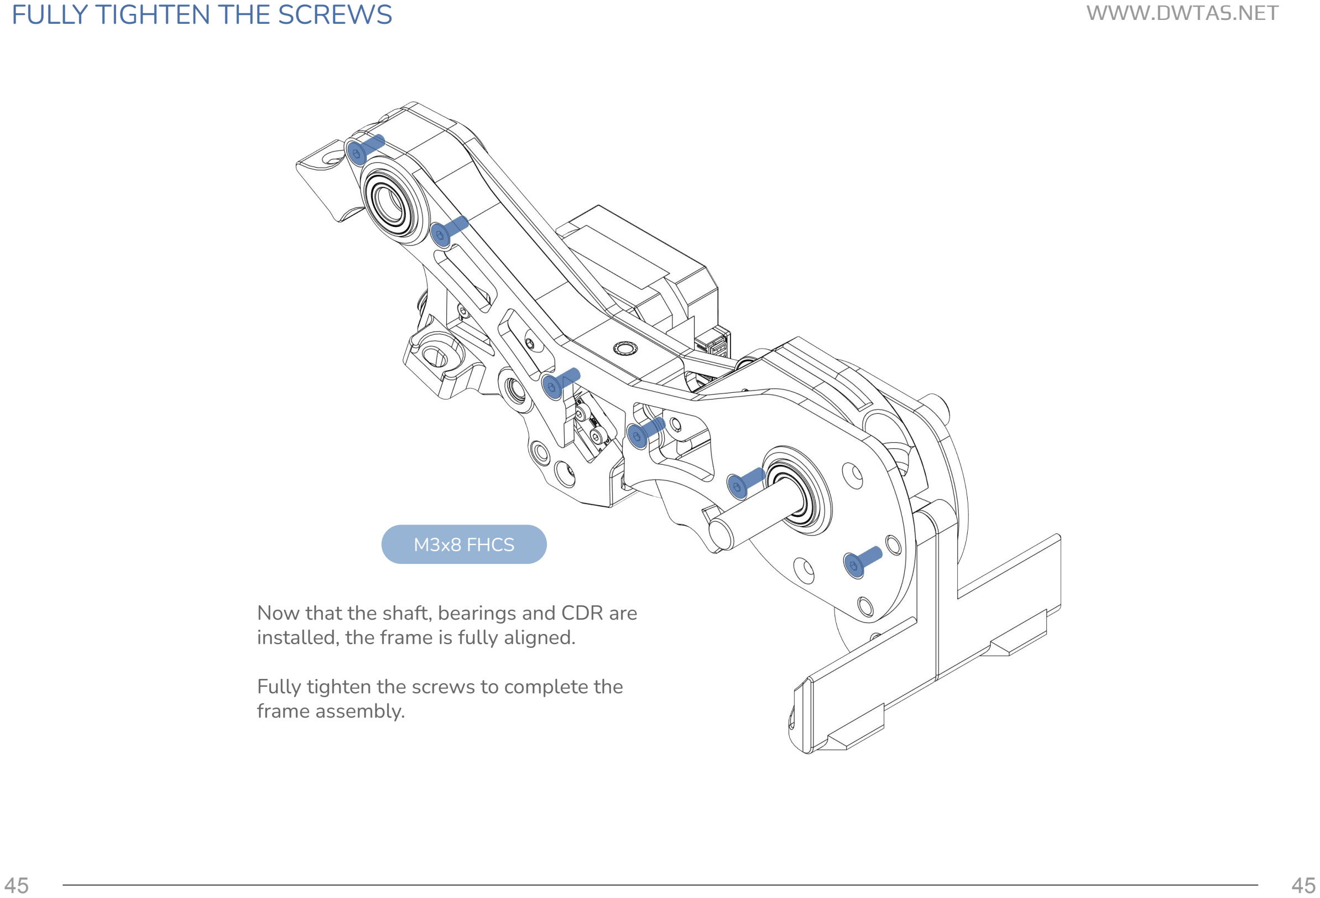
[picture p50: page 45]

M3x8 FHCS

Now that the shaft, bearings and CDR are installed, the frame is fully aligned.

Fully tighten the screws to complete the frame assembly.

ADD THE SQUARE NUT AND SCREW TO BOTH WHEELS | WWW.DWTAS.NET

Screw needs to be finger tight and not fully flush with the frame to allow the wheels to be inserted on the

ADD THE RUBBER BANDS TO BOTH WHEELS | WWW.DWTAS.NET
Rubber band | Bike tube
Repeat x2 | Repeat x2

OR

There are two options for creating a “grip surface” on the driving wheels. Rubber bands or a cut bike tube. For ease of assembly rubber bands are recommended.

PLACE AND SECURE THE WHEELS TO THE ASSEMBLY | WWW.DWTAS.NET

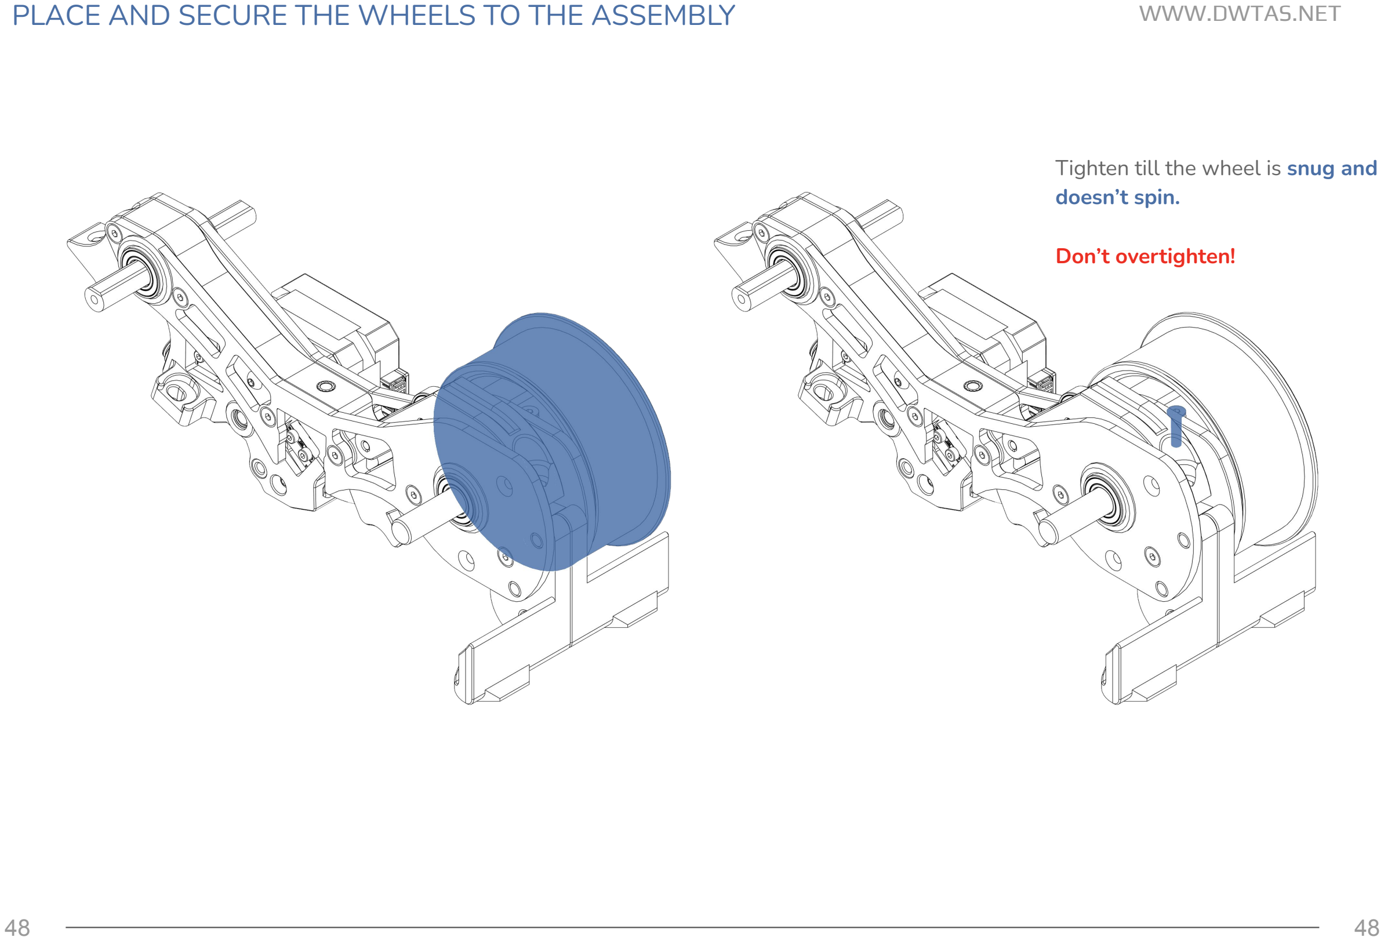
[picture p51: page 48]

Tighten till the wheel is snug and doesn’t spin.

Don’t overtighten!

PLACE AND SECURE WHEEL ON ASSEMBLY | WWW.DWTAS.NET

Tighten till the wheel is snug and doesn’t spin.

Don’t overtighten!

CLEAN UP THE SACRIFICIAL BRIDGE ON BOTH IDLER ROLLERS | WWW.DWTAS.NET

PLACE AND SECURE IDLER ROLLER ON ASSEMBLY | WWW.DWTAS.NET

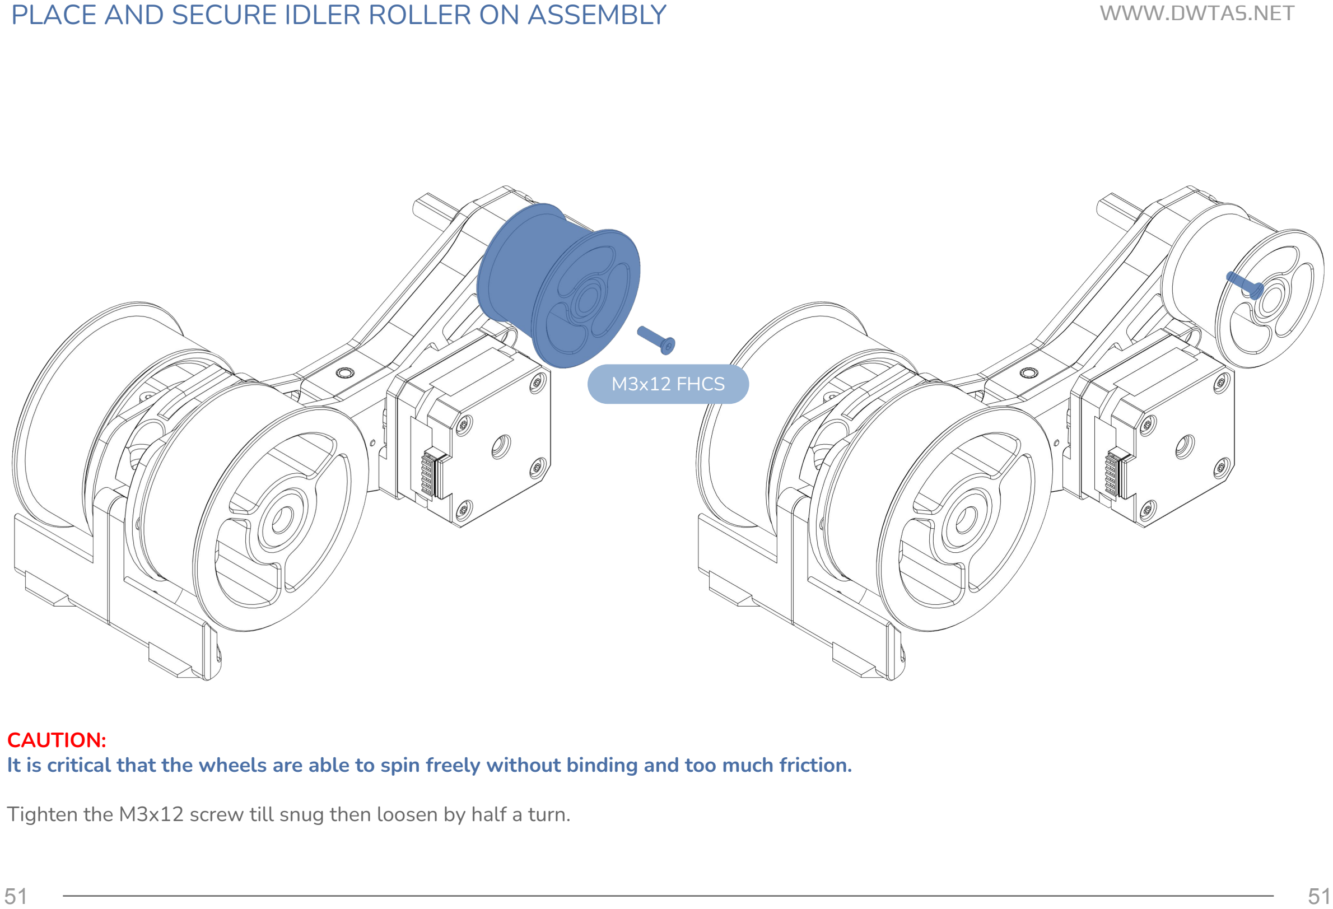
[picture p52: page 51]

M3x12 FHCS

CAUTION:
It is critical that the wheels are able to spin freely without binding and too much friction.

Tighten the M3x12 screw till snug then loosen by half a turn.

PLACE AND SECURE IDLER ROLLER ON ASSEMBLY | WWW.DWTAS.NET

M3x12 FHCS

CAUTION:
It is critical that the wheels are able to spin freely without binding and too much friction.

Tighten the M3x12 screw till snug then loosen by half a turn.

INSERT THE REAR PTFE TUBE | WWW.DWTAS.NET

Rear (R) PTFE Tube

ALIGN THE BMG GEAR TO THE FILAMENT PATH | WWW.DWTAS.NET

CAUTION:
It is critical that the BMG gear is aligned with the filament path and that it does not press against the MR85 bearing. Doing so will increase friction in the system and reduce the unit’s reliability.

Add some filament manually to the assembly. Move the filament back and forth till the BMG gear centres with the path. Tighten down. Ensure there is approximately 0.1-0.2mm gap between the BMG gear and the bearing.

INSERT & SECURE TENSION ARM BEARING | WWW.DWTAS.NET

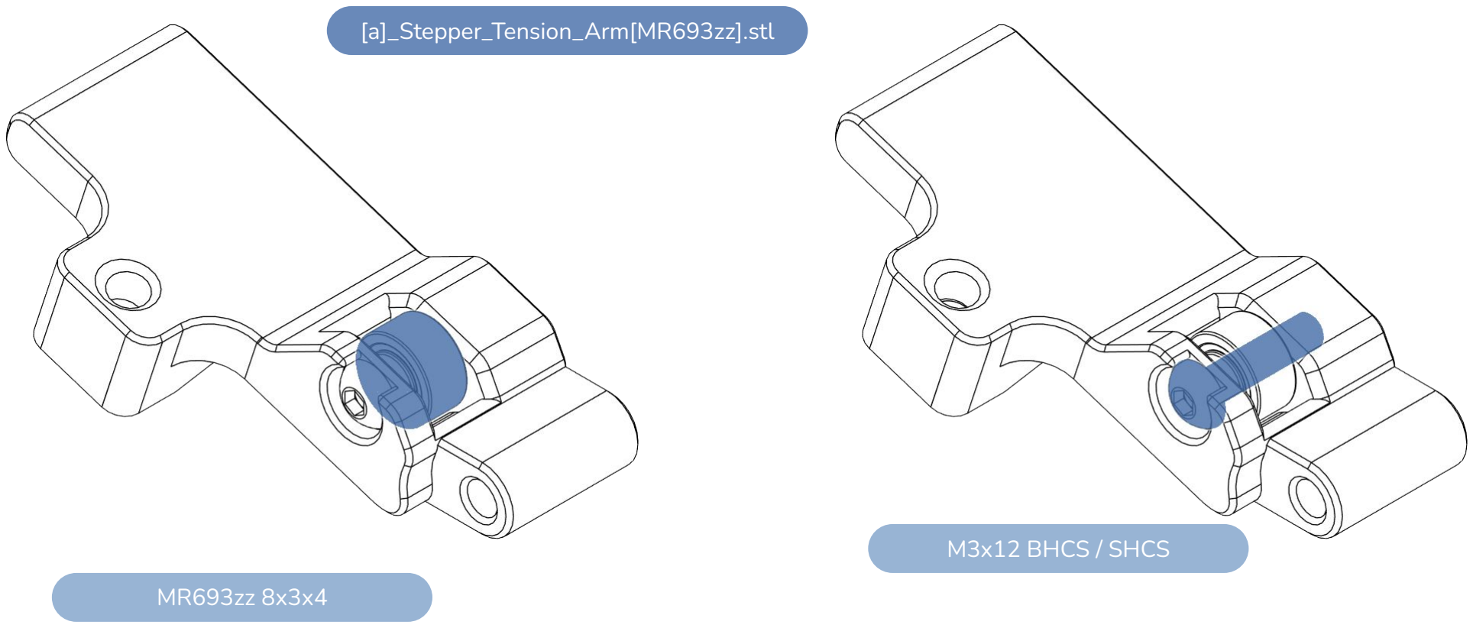
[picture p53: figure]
M3x12 BHCS / SHCS; [a]_Stepper_Tension_Arm[MR693zz].stl

CAUTION:
It is critical that the BMG idler bearing is able to spin freely with little/no friction and no binding.

Tighten the M3x12 screw till snug then loosen by half a turn. The bearing may be able to wiggle in the assembly. That is perfectly fine.

PLACE THE TENSIONING ARM INTO POSITION | WWW.DWTAS.NET

SECURE THE TENSIONING ARM | WWW.DWTAS.NET

M3x20 BHCS

CAUTION:
It is critical that the tensioning arm is able to move with little/no friction and no binding. It should be able to open under its own weight.

Tighten the M3x20 screw till snug then loosen by half a turn. The arm may be able to wiggle in the assembly. That is perfectly fine.

ADD TENSION ARM SCREW | WWW.DWTAS.NET

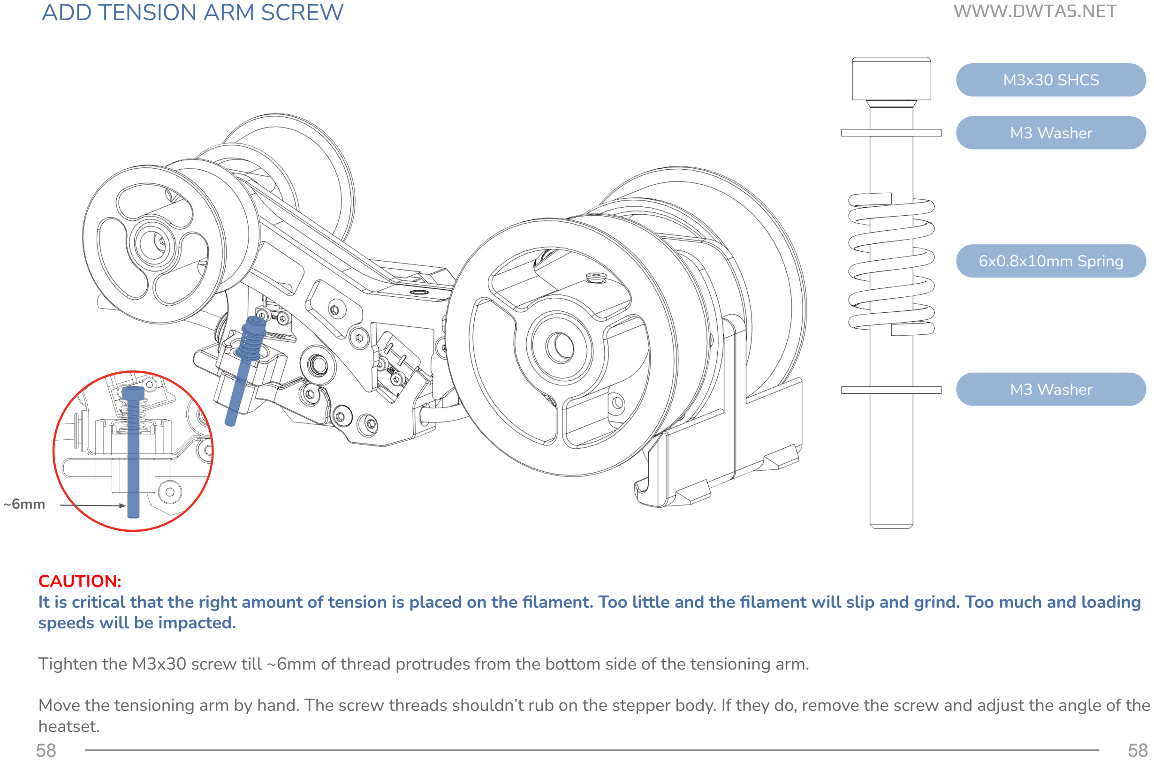
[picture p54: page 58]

M3x30 SHCS

M3 Washer

M3 Washer

6x0.8x10mm Spring

CAUTION:
It is critical that the right amount of tension is placed on the filament. Too little and the filament will slip and grind. Too much and loading speeds will be impacted.

Tighten the M3x30 screw till ~6mm of thread protrudes from the bottom side of the tensioning arm.

Move the tensioning arm by hand. The screw threads shouldn’t rub on the stepper body. If they do, remove the screw and adjust the angle of the heatset.

~6mm

ADD FRONT TENSIONER SCREW | WWW.DWTAS.NET

M3x30 SHCS

M3 Washer

M3 Washer

6x0.6x15mm Spring

CAUTION:
It is critical that the right amount of tension is placed on the filament by the CDR. Too little and the spool will not rewind tightly. Too much and the filament may break at the CDR.

Without any filament loaded, tighten the M3x30 screw till the top washer barely touches the screw head. The screw may feel loose. That is perfectly fine.

INSERT THE NEOPIXEL LED INTO ITS HOLDER | WWW.DWTAS.NET

Step 1: Pass led
through cover hole
Step 2: Rotate led into
position
Step 3: Push led into
position using a hex key

LED_holder.stl

INSERT THE BME280 / ATH20 SENSOR INTO ITS HOLDER | WWW.DWTAS.NET

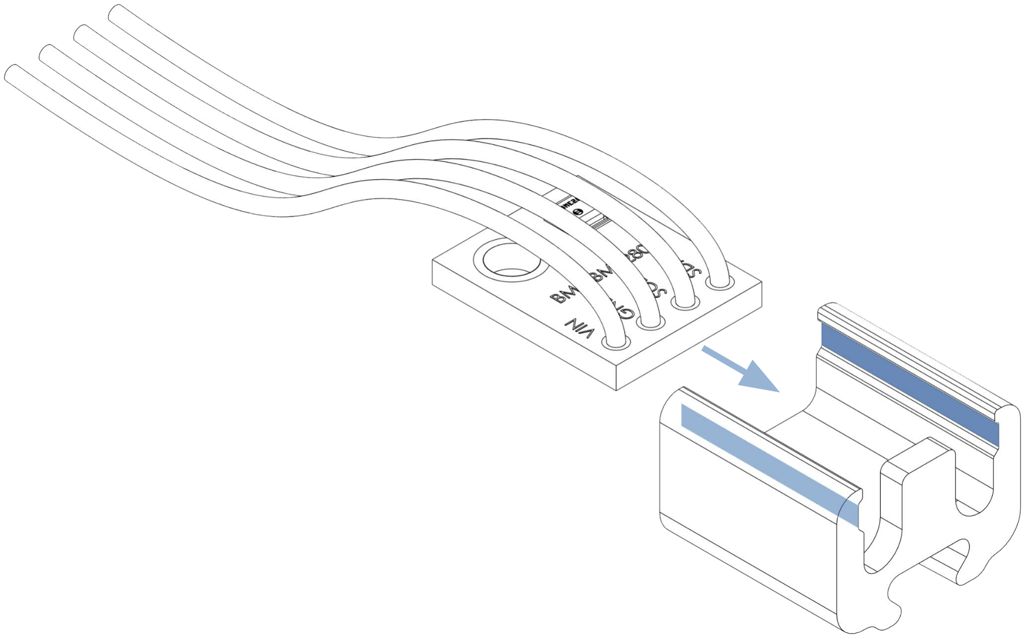
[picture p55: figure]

[a]_BME280_Holder.stl

ATTACH THE BME280 / AHT20 SENSOR ASSEMBLY TO THE LED HOLDER | WWW.DWTAS.NET

PLACE & SECURE THE LED HOLDER | WWW.DWTAS.NET

M3x8 SHCS

WWW.DWTAS.NET

# CHAPTER 3: CABLE MANAGEMENT

CONNECT SWITCHES TO HATCH BOARD | WWW.DWTAS.NET

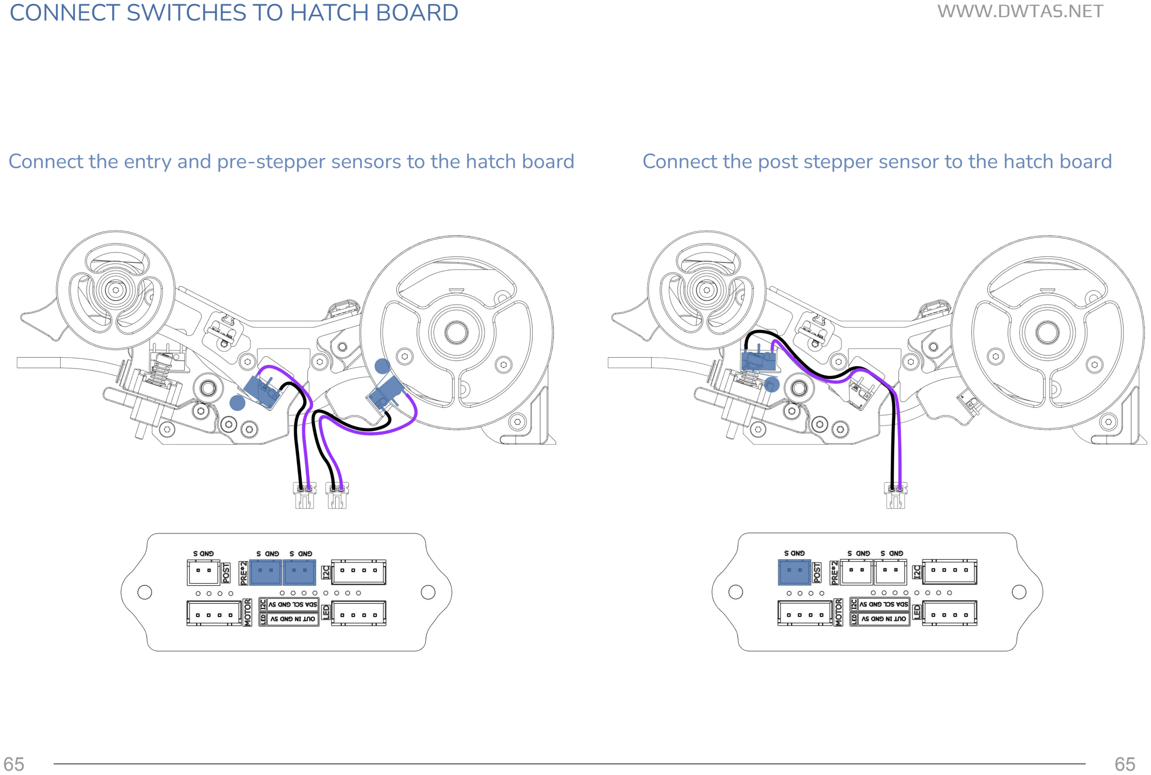
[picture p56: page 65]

Connect the entry and pre-stepper sensors to the hatch board Connect the post stepper sensor to the hatch board

CONNECT SENSORS TO HATCH BOARD | WWW.DWTAS.NET

Connect the environment sensor to the hatch board | Connect the neopixel to the hatch board

SECURE THE WIRES | WWW.DWTAS.NET

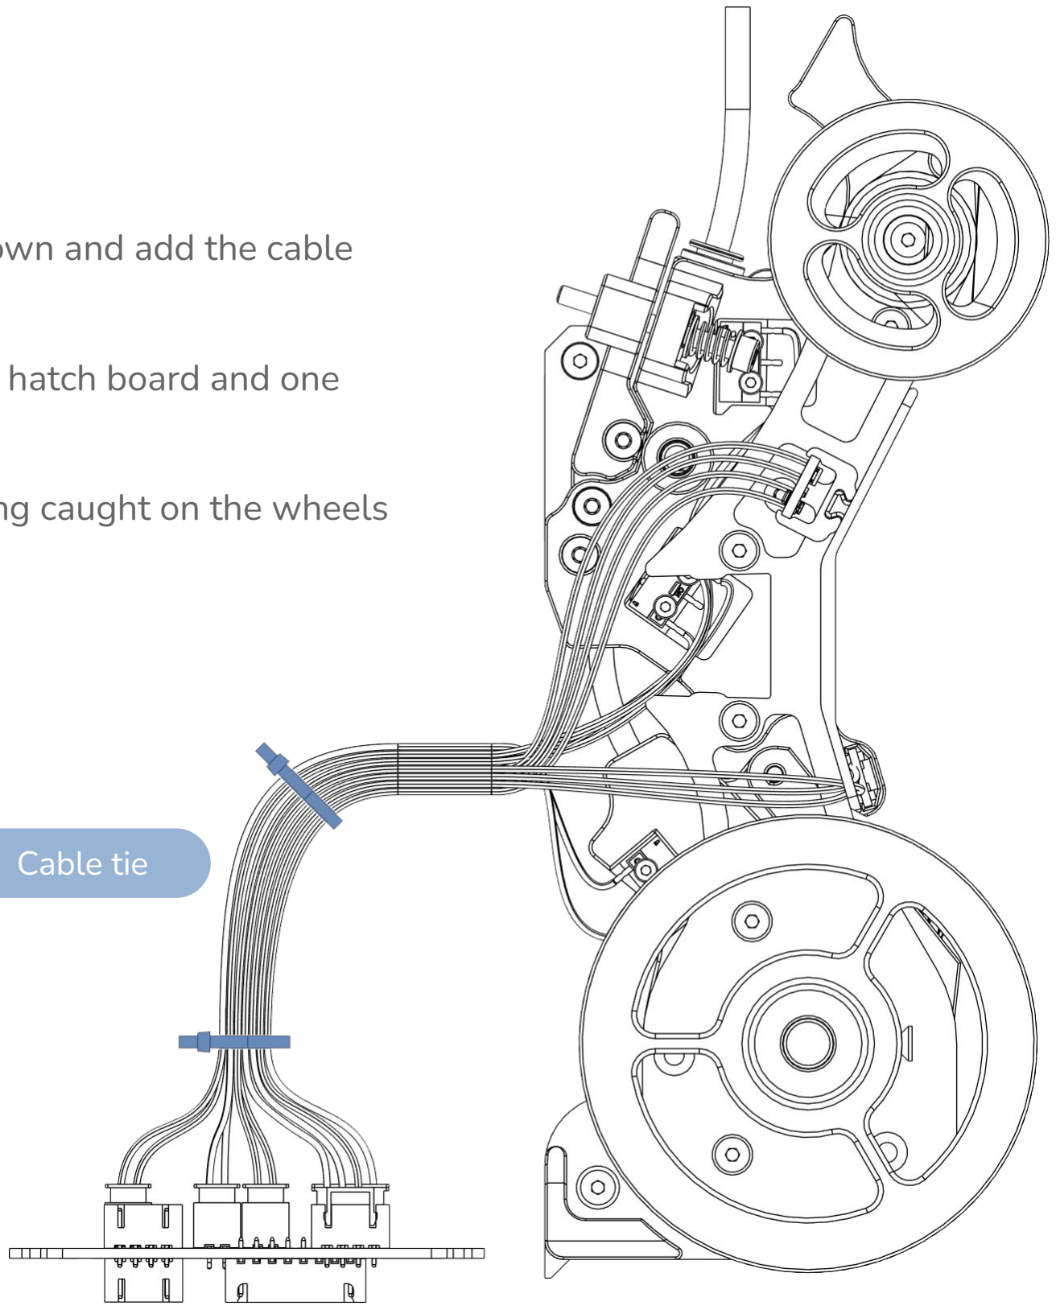
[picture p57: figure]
Cable tie

Stand the unit and hatch board as shown and add the cable ties.

One cable tie needs to be close to the hatch board and one towards the filamentalist assembly.

This will prevent the wires from getting caught on the wheels during operation.

DISCONNECT ALL THE WIRES FROM THE HATCH BOARD | WWW.DWTAS.NET

THANK YOU | WWW.DWTAS.NET

## Join us on Discord !

https://discord.gg/WuxGVTzu5p

## See my other projects

https://dwtas.net/

## EMU Github

https://github.com/DW-Tas/EMU

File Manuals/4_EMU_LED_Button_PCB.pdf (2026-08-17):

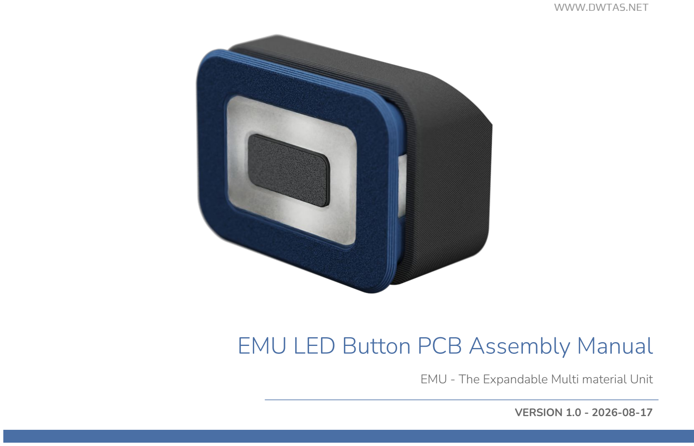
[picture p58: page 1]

WWW.DWTAS.NET

# EMU LED Button PCB Assembly Manual

### EMU - The Expandable Multi material Unit

VERSION 1.0 - 2026-08-17

PART PRINTING GUIDELINES | WWW.DWTAS.NET

2

3D PRINTING PROCESS
Fused Deposition Modeling (FDM)

INFILL TYPE
Gyroid or Cubic

MATERIAL
ABS/ASA. Glass and CF filled material are compatible. Use natural ABS for the diffuser.

INFILL PERCENTAGE
Recommended: 15%

LAYER HEIGHT
Mandatory: 0.2mm, including first layer!

WALL COUNT
Recommended: 4

EXTRUSION WIDTH
0.4mm, Arachne slicing engine.
Infill can be printed wider (0.45/0.48) to increase layer bonding.

SOLID TOP/BOTTOM LAYERS
Recommended: 5

SHRINKAGE COMPENSATION
Parts are not compensated for filament shrinkage. Calibrate your filament shrinkage compensation in the slicer before printing.

2

To have the best chance of success, the following print settings are highly recommended.

ASSEMBLING THE PCB | WWW.DWTAS.NET

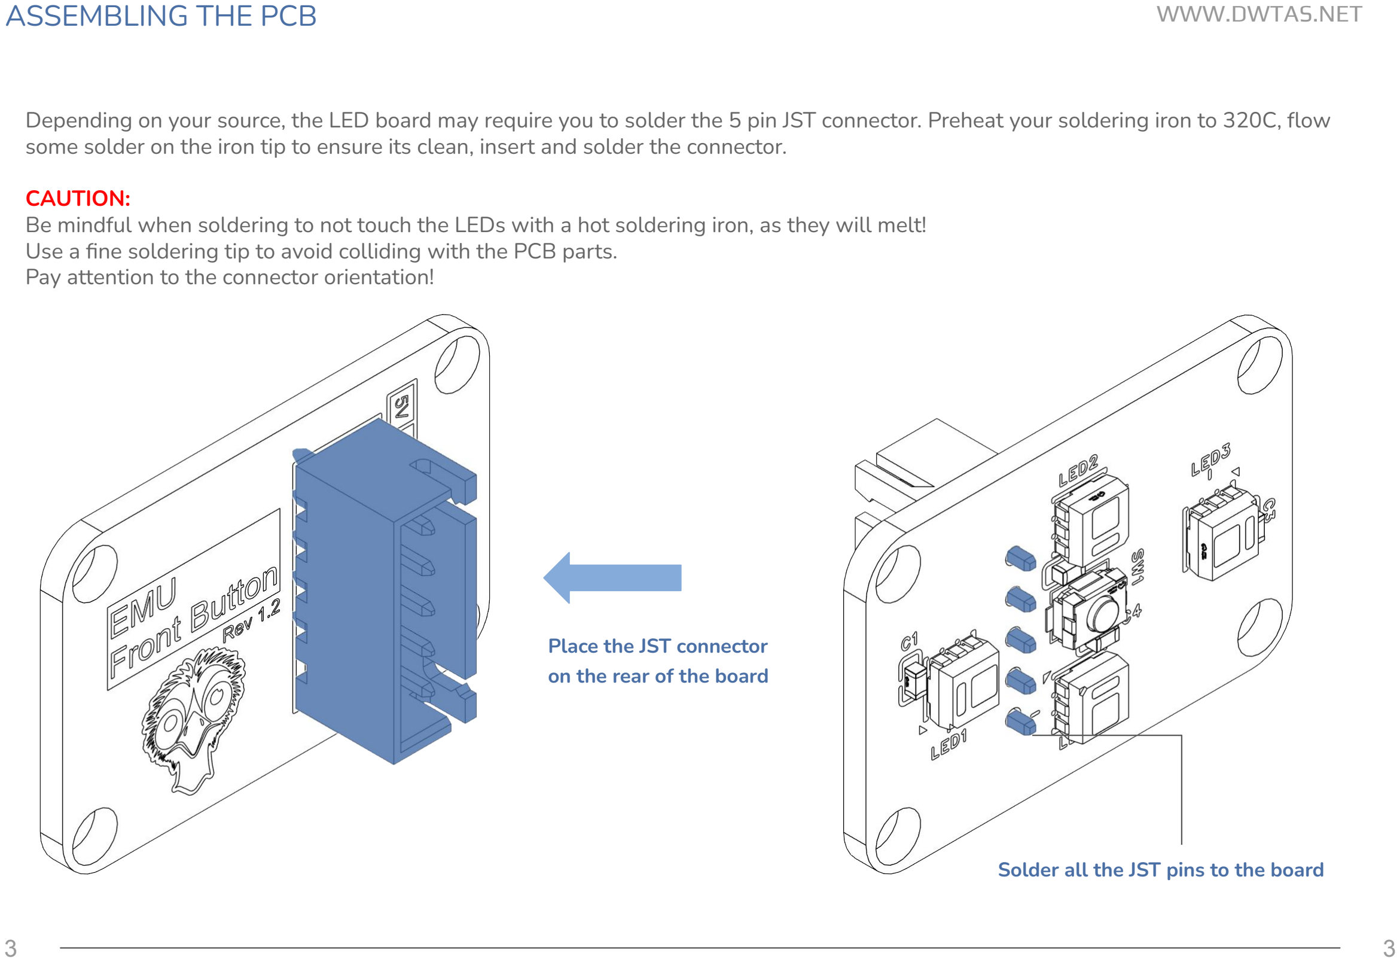
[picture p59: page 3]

Depending on your source, the LED board may require you to solder the 5 pin JST connector. Preheat your soldering iron to 320C, flow some solder on the iron tip to ensure its clean, insert and solder the connector.

CAUTION:
Be mindful when soldering to not touch the LEDs with a hot soldering iron, as they will melt!
Use a fine soldering tip to avoid colliding with the PCB parts.
Pay attention to the connector orientation!

Place the JST connector
on the rear of the board

Solder all the JST pins to the board

LED BUTTON ASSEMBLY | WWW.DWTAS.NET

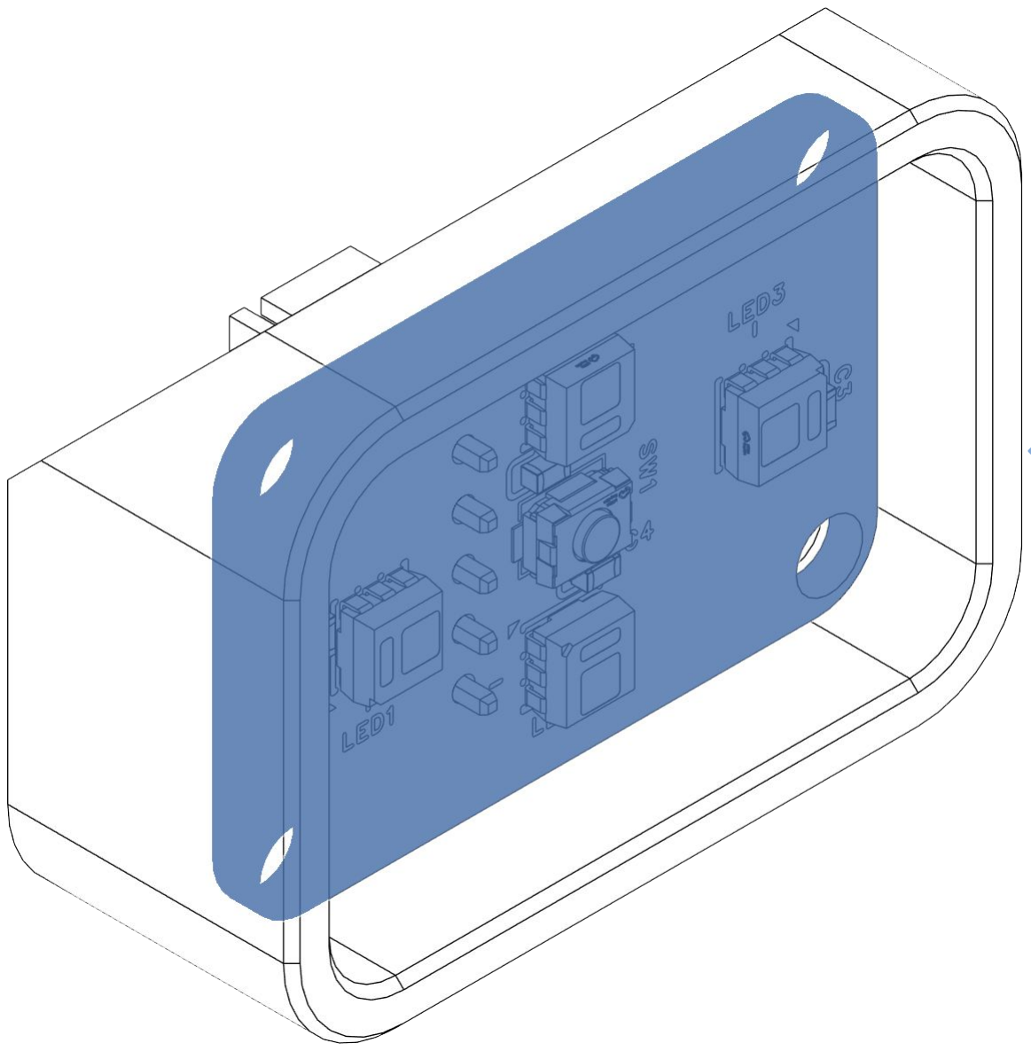
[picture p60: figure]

Place the LED Button PCB in the Button Rear assembly.

Make sure it sits flush with the rear surface.

LED BUTTON ASSEMBLY | WWW.DWTAS.NET

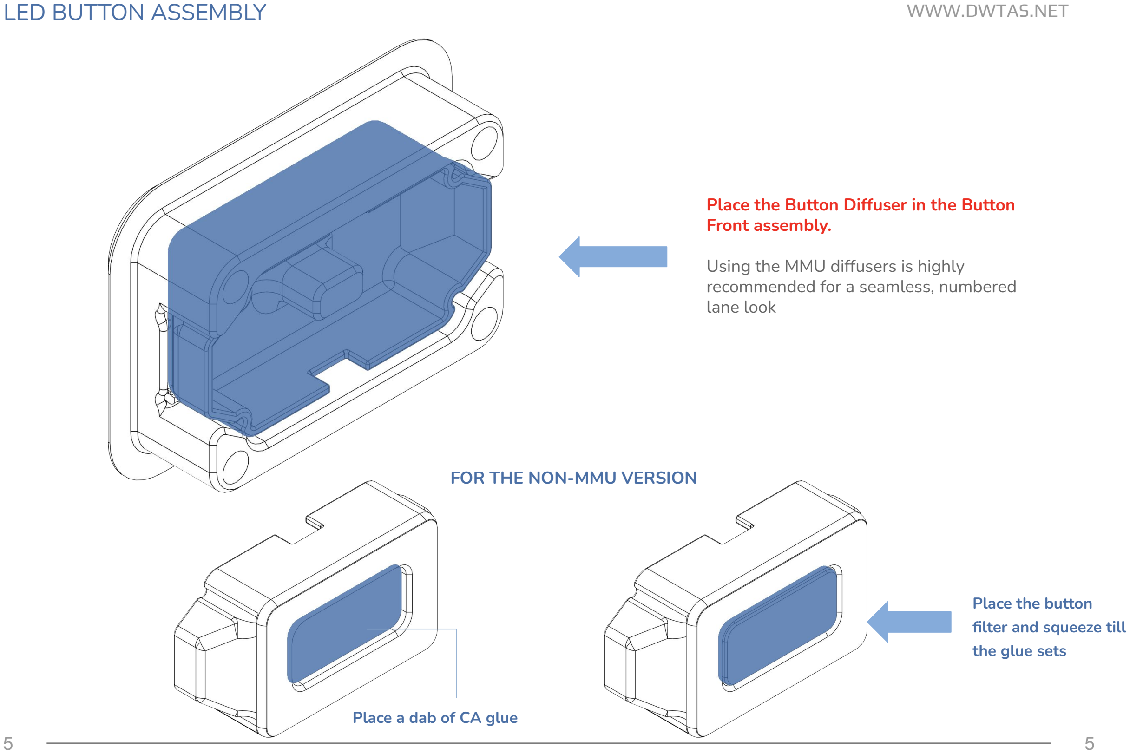
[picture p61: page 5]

Place the Button Diffuser in the Button Front assembly.

Using the MMU diffusers is highly recommended for a seamless, numbered lane look

FOR THE NON-MMU VERSION

Place a dab of CA glue

Place the button
filter and squeeze till
the glue sets

LED BUTTON ASSEMBLY | WWW.DWTAS.NET

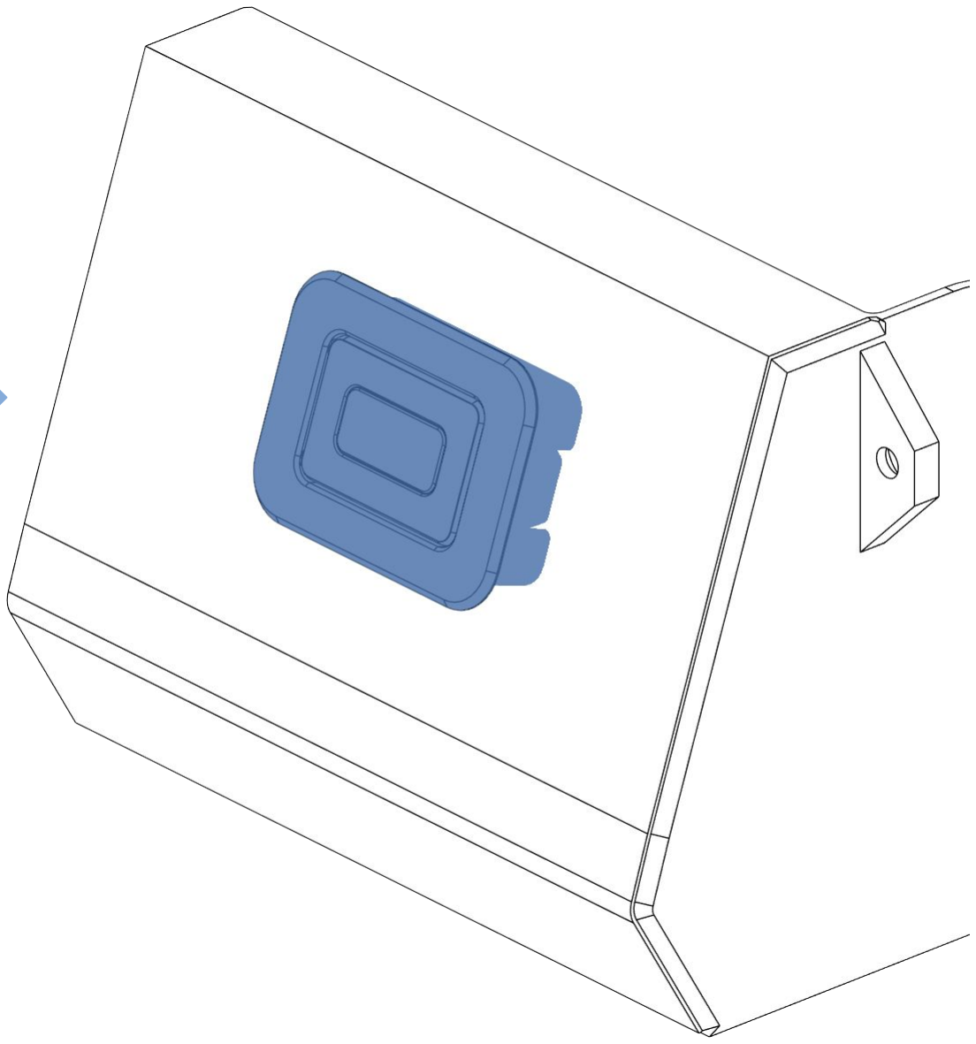
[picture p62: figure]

Place the front assembly in the base.

Tilt the base slightly so that the diffuser doesn’t fall out.

LED BUTTON ASSEMBLY | WWW.DWTAS.NET

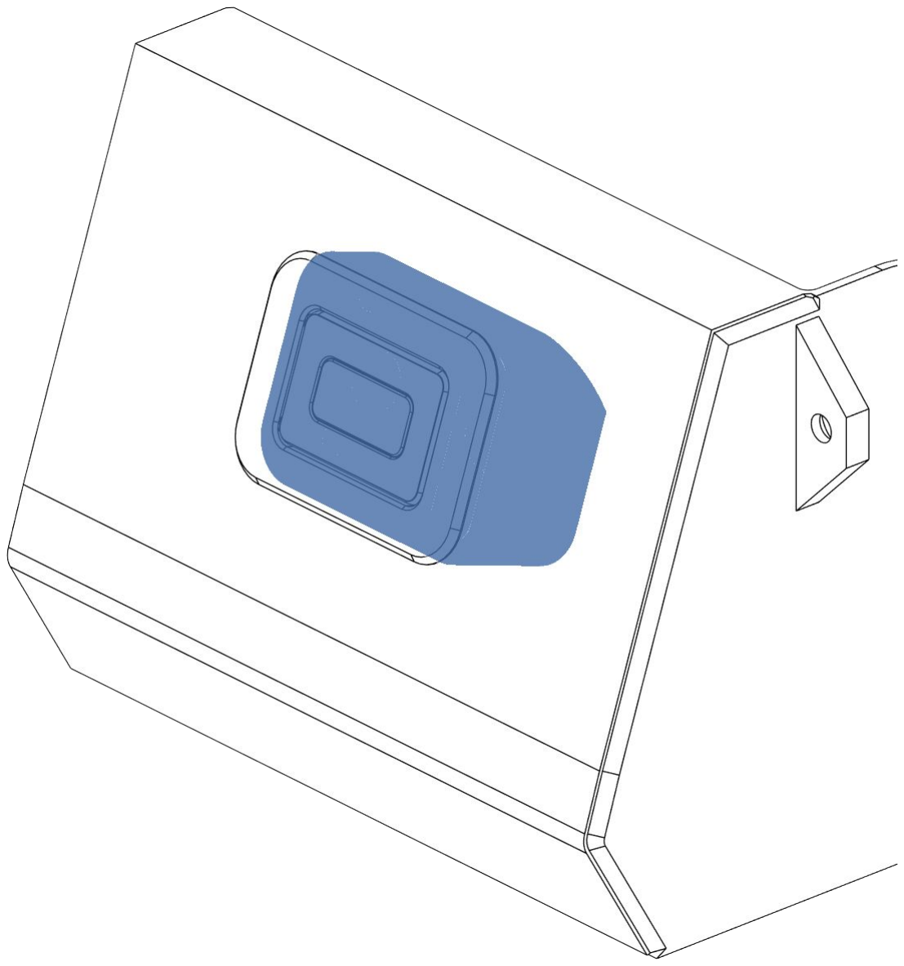
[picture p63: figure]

Place the rear of assembly in the base and squeeze the parts so they fully seat against each other.

LED BUTTON ASSEMBLY | WWW.DWTAS.NET

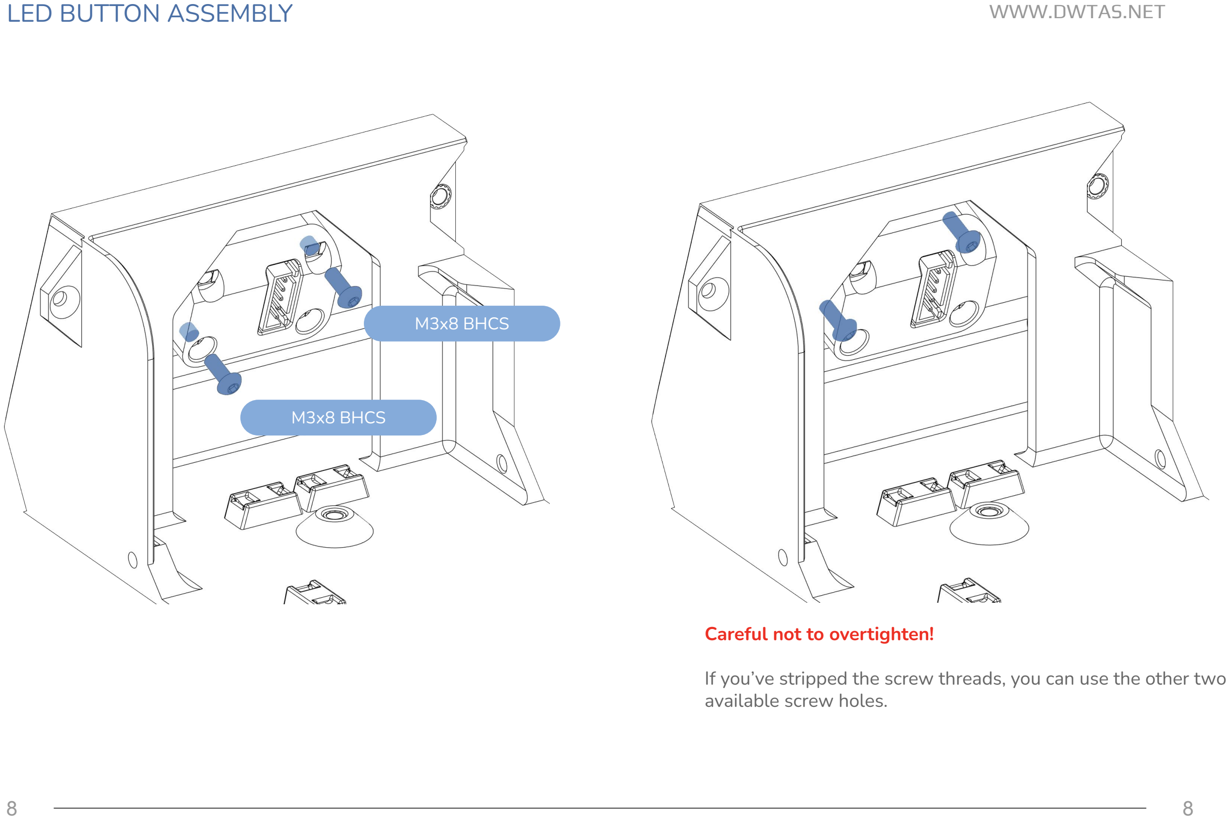
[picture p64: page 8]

Careful not to overtighten!

If you’ve stripped the screw threads, you can use the other two available screw holes.

M3x8 BHCS

M3x8 BHCS

LED BUTTON ASSEMBLY | WWW.DWTAS.NET

EBB42:
5V and Ground: Neopixel - dupont connector
Neopixel In (DIN): Neopixel - dupont connector (PD3)

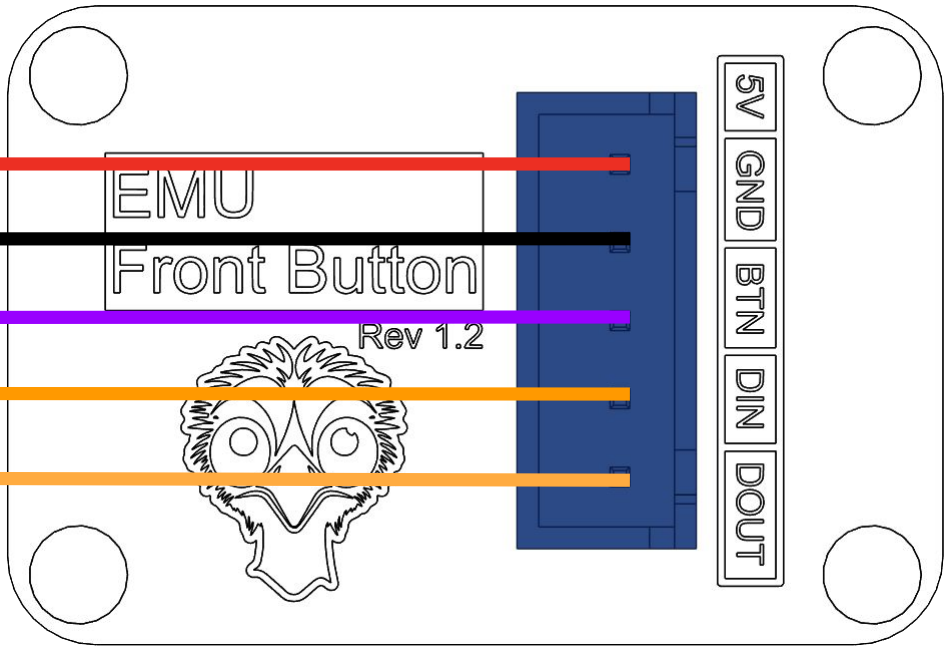
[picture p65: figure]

Neopixel Out (DOUT): connect to WAGO and then to the hatch PCB LED In Button signal: Endstop port - JST PH (PB6)

EMU SLB
5V and Ground: LED port
Neopixel In (DIN): LED port (PA4) Neopixel Out (DOUT): Not used! Button signal: STP4 port (PC6)

Connect the Button PCB to the remaining electronics

All wires are 30cm long, JST XH terminated on the PCB side. Depending on your choice of board, terminate either with JST XH (EMU SLB), or dupont and JST PH connectors (EBB 42).

5V - connect to the LED header on the board

Ground - connect to the LED header on the board

Button Signal (S) - connect to an endstop pin on the board

Neopixel In (DIN) - connect to the LED header on the board

Neopixel Out (DOUT) - see below

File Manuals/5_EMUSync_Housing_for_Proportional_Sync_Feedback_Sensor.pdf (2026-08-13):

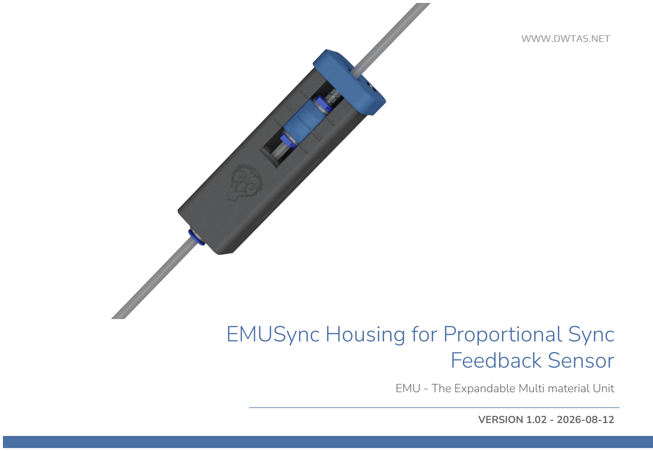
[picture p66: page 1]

WWW.DWTAS.NET

# EMUSync Housing for Proportional Sync Feedback Sensor

### EMU - The Expandable Multi material Unit

VERSION 1.02 - 2026-08-12

WWW.DWTAS.NET

2

To have the best chance of success, the following print settings are highly recommended.

3D PRINTING PROCESS
Fused Deposition Modeling (FDM)

INFILL TYPE
Gyroid or Cubic

MATERIAL
ABS/ASA. Glass and CF filled material are compatible.

INFILL PERCENTAGE
Recommended: 15%-40%

LAYER HEIGHT
Mandatory: 0.2mm, including first layer!

WALL COUNT
Recommended: 4
One Wall Top and Bottom surface

EXTRUSION WIDTH
0.4mm, Arachne slicing engine.
Infill can be printed wider (0.45/0.48) to increase layer bonding.

SOLID TOP/BOTTOM LAYERS
Recommended: 5

SHRINKAGE COMPENSATION
Parts are not compensated for filament shrinkage.
Calibrate your filament shrinkage compensation in the slicer before printing.

2

## PART PRINTING GUIDELINES

ECAS CONNECTORS PREPARATION | WWW.DWTAS.NET

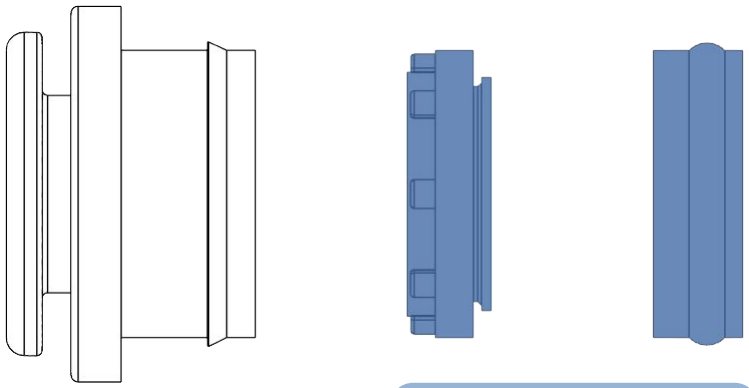
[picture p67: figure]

Remove

CAUTION:
Whenever we are using ECAS in this manual, the seal retainer and the seal should be removed

CUT THE PTFE RAILS TO SIZE | WWW.DWTAS.NET

Cut here

Insert a 4mm OD, 2.5mm ID piece of bowden tube in the cutting jig. Cut flush with the body using a blade.

Repeat for the second rail, creating two cut to size “rails”.


PTFE Cutter and Length Tool[PSF].stl

CHAMFER THE PTFE TUBES | WWW.DWTAS.NET


Filament path

CAUTION:
To ensure smooth feeding of the filament, it is recommended that the inlet side of the PTFE tubes are slightly chamfered. This can be done using a countersinking tool or a 4mm drill bit.

For the PSF, this means the side of the tube that is inserted in the combiner exit and the side of the tube that is inserted in the EMUSync exit.

INSERT HEATSET INSERTS; WWW.DWTAS.NET; M3 Heat Set Insert; EMUSync_main_body[PSF].stl

INSERT ECAS FITTINGS IN MAIN BODY | WWW.DWTAS.NET

ECAS04; CAUTION:

Remember to remove and discard the retainer and the seal

INSERT ECAS FITTING IN THE SHUTTLE | WWW.DWTAS.NET


ECAS04

ECAS04; CAUTION:; [a]_ECAS_trigger[PSF].stl

Remember to remove and discard the retainer and the seal

INSERT MAGNET IN THE SHUTTLE | WWW.DWTAS.NET


The orientation of the magnet doesn’t matter, the software will auto calibrate no matter the orientation.

Magnet 4x15mm N35

INSERT THE BOWDEN TUBE IN THE SHUTTLE | WWW.DWTAS.NET


Use the cutting jig to keep the right side ECAS fitting compressed. While keeping it compressed, slide the PTFE tube in from the left side.

Push through until the tube bottoms out in the jig.

INSERT THE PTFE RAILS | WWW.DWTAS.NET


Insert the two PTFE rails into position. Push from the top and slide down until they have bottomed out.

Try to not bend the tubes when inserting!

INSERT THE SHUTTLE | WWW.DWTAS.NET


Slide the shuttle into position between the two PTFE rails you just placed.

SECURE THE TUBE WITH THE ECAS CLIPS | WWW.DWTAS.NET


ECAS Clip

ECAS Clip

Place the ECAS clips to secure the tube in place. Be mindful of their orientation!

PLACE THE COMPRESSION SPRING | WWW.DWTAS.NET


Spring
0.4x6x25mm

PLACE AND SECURE THE END CAP | WWW.DWTAS.NET


M3x8mm BHCS*

*M3x8 SHCS screws can also be used.

[a]_End_cap[PSF].stl

INSERT THE PSF BOARD | WWW.DWTAS.NET


M2x6mm SHCS*

PSF Board

M2x6mm SHCS*

*M2 self tapping screws can also be used

PLACE AND SECURE THE CABLE COVER | WWW.DWTAS.NET


M3x8mm BHCS*

*M3x8 SHCS screws can also be used.

[a]_Cable_cover[PSF].stl

TENSION VS COMPRESSION | WWW.DWTAS.NET


Tension | Compression

THANK YOU | WWW.DWTAS.NET

## Join us on Discord !

https://discord.gg/WuxGVTzu5p

## See my other projects

https://dwtas.net/

## EMU Github

https://github.com/DW-Tas/EMU

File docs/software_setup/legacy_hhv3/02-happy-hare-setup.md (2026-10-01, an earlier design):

# Happy Hare Setup (Happy Hare v3 – legacy)

> [!WARNING]
> **Legacy guide for Happy Hare v3.** This page is kept for existing Happy Hare v3 installs only. For new installs, or to upgrade to Happy Hare v4, follow the [EMU Getting Started guide for Happy Hare v4](https://moggieuk.github.io/Happy-Hare-Doc/GettingStarted-EMU/) (via [Step 4: Software Setup](/docs/software_setup/02-software-setup.md)). See the [legacy v3 guide index](/docs/software_setup/legacy_hhv3) for the rest of the v3 guides.

This section covers installing and configuring Happy Hare for the EMU. It is meant to be read in conjunction with the [Happy Hare wiki](https://github.com/moggieuk/Happy-Hare/wiki).

## Table of Contents

- [Installing Happy Hare](#installing-happy-hare)
- [Configuring the EMU hardware](#configuring-the-emu-hardware)
  - [Update your printer.cfg](#update-your-printercfg)
  - [Update mmu/base/mmu.cfg](#update-mmubasemmucfg)
  - [Update mmu/base/mmu_hardware.cfg](#update-mmubasemmu_hardwarecfg)
  - [Update mmu/addons/mmu_eject_buttons_hw.cfg](#update-mmuaddonsmmu_eject_buttons_hwcfg)
  - [Upload the emu_macros.cfg file and reference it in your printer.cfg](#upload-the-emu_macroscfg-file-and-reference-it-in-your-printercfg)
  - [Save, restart and confirm lanes are visible](#save-restart-and-confirm-lanes-are-visible)
- [Configuring Happy Hare parameters](#configuring-happy-hare-parameters)
- [Configuring PSF and Flowguard (optional)](#configuring-psf-and-flowguard)
- [EMUSync PSF insights (optional)](#emusync-psf-insights)

## Installing Happy Hare

Install Happy Hare. More detailed instructions can be found here: <https://github.com/moggieuk/Happy-Hare/wiki/Installation>

```bash
cd ~
git clone https://github.com/moggieuk/Happy-Hare.git
cd ~/Happy-Hare
./install.sh -i
```

**Select MMU:** Pick option 16 - Other/Custom. <br/><br/>
<p align="center">
  Installer screen: Pick option 16 - Other/Custom
</p>

**Select MMU type:** Pick option 7 - Type-B (multiple filament drive steppers) with individual post-gear sensors, No Encoder <br/><br/>
<p align="center">
  Installer screen: Pick option 7 - Type-B with individual post-gear sensors, no encoder
</p>

**Select lane number:** Type the number of lanes you have set up. In my example below it is 8. <br/><br/>
<p align="center">
  Enter number of lanes (example: 8)
</p>

**Select the board used:** Pick option 15 - Not in list / Unknown <br/><br/>
<p align="center">
  Select board: option 15 Not in list / Unknown
</p>

**LED Support:** Enable LED support <br/><br/>
<p align="center">
  Enable LED support
</p>

**Endless Spool Support:** Enable Endless Spool support <br/><br/>
<p align="center">
  Enable Endless Spool support
</p>

**Include all the MMU config files:** Include all mmu config files in the printer.cfg <br/><br/>
<p align="center">
  Include MMU config files in printer.cfg
</p>

**(Optional) Mini 12864 screen support:** If you have a Mini 12864 screen, enable the Happy Hare screen menu <br/><br/>
<p align="center">
  Enable Happy Hare menu for Mini 12864 (optional)
</p>

**Default pause/resume macros:** Include the default pause/resume macros from Happy Hare. Once the installation is complete, make sure you disable/remove any custom pause/resume macros that you may have in your existing Klipper installation! <br/><br/>
<p align="center">
  Include default pause/resume macros from Happy Hare
</p>

**EREC support:** Decline the installation of the EREC filament cutter <br/><br/>
<p align="center">
  Decline EREC filament cutter installation
</p>

**Moonraker.conf update:** Make sure your moonraker.conf contains [mmu_server] (should be inserted by HappyHare setup). Update it as per the below if it doesn't match:

```ini
[file_manager]
enable_object_processing: True

[mmu_server]
enable_file_preprocessor: True
enable_toolchange_next_pos: True
update_spoolman_location: True
```


<br/><br/>
Baseline setup is now complete!
<br/><br/>

## Configuring the EMU hardware

### Update your printer.cfg

Include the below items at the top of your printer.cfg. The mmu/base and client macros should already exist, following the setup wizard.

```ini
[include mmu/base/*.cfg]
[include mmu/addons/mmu_eject_buttons.cfg]
[include mmu/optional/client_macros.cfg]
[include emu_macros.cfg] # download this file from the EMU repo and upload to your printer
# [include mmu/addons/blobifier.cfg] # Enable this if you have a blobifier set up
```

### Update mmu/base/mmu.cfg

The Happy hare installer generates a generic mmu.cfg file that needs re-writing for the EMU.

**Step 1: Clear the mmu.cfg file.** <br/><br/>
Start by completely deleting the content of that file and hitting save.

**Step 2: Update mmu.cfg with the EMU mcu boards definitions** <br/><br/>
For each lane you will need one distinct mcu mmu block defining the board name and the canbus UUID as noted earlier. In the example below I am using an 8 lane configuration. For a two lane setup, for example, you'd use `[mcu mmu0]` and `[mcu mmu1]` only.

```ini
[mcu mmu0]
canbus_uuid: your uuid
canbus_interface: can0 # if you have multiple canbus buses, define here which canbus has the EMU units on it.

[mcu mmu1]
canbus_uuid: your uuid
canbus_interface: can0

[mcu mmu2]
canbus_uuid: your uuid
canbus_interface: can0

[mcu mmu3]
canbus_uuid: your uuid
canbus_interface: can0

[mcu mmu4]
canbus_uuid: your uuid
canbus_interface: can0

[mcu mmu5]
canbus_uuid: your uuid
canbus_interface: can0

[mcu mmu6]
canbus_uuid: your uuid
canbus_interface: can0

[mcu mmu7]
canbus_uuid: your uuid
canbus_interface: can0
```

**Step 3 - Update mmu.cfg with the EMU mcu board pin aliases** <br/><br/>
**For the EBB42/36:** After the board definitions, insert the board pin aliases.

```ini
[board_pins mmu]
mcu: mmu0, mmu1, mmu2, mmu3, mmu4, mmu5, mmu6, mmu7
aliases:
    MMU_GEAR_UART=PA15,
    MMU_GEAR_STEP=PD0,
    MMU_GEAR_DIR=PD1,
    MMU_GEAR_ENABLE=PD2,
    MMU_GEAR_DIAG=,

    MMU_NEOPIXEL=PD3,
    MMU_NEOPIXEL_LOGO=,

    MMU_PRE_GATE=PB7,
    MMU_POST_GEAR=PB5,

    MMU_TENSION=PB8,
    MMU_COMPRESSION=PB9,

    MMU_TH=PA3,

    MMU_FAN=PA0,

    EJECT_BUTTON=PB6,
```

**For the Solo Lane Board (SLB):** After the board definitions, insert the board pin aliases.

```ini
[board_pins mmu]
mcu: mmu0, mmu1, mmu2, mmu3, mmu4, mmu5, mmu6, mmu7
aliases:
    MMU_GEAR_UART=PB6,
    MMU_GEAR_STEP=PB5,
    MMU_GEAR_DIR=PB4,
    MMU_GEAR_ENABLE=PB7,
    MMU_GEAR_DIAG=,

    MMU_NEOPIXEL_BOX=PA2,
    MMU_NEOPIXEL_BUTTON=PA4,

    MMU_PRE_GATE=PA1,
    MMU_POST_GEAR=PA0,

    MMU_TENSION=PB1, # First lane has the sync feedback sensor attached to it!
    MMU_COMPRESSION=PB0, # First lane has the sync feedback sensor attached to it!
    MMU_TH=PA3, # First lane has the PFS sensor attached to it!

    MMU_FAN=PA15,
    EJECT_BUTTON=PB2,
```

### Update mmu/base/mmu_hardware.cfg

**Step 1: Clear the mmu_hardware.cfg file.** <br/><br/>
Start by completely deleting the content of that file and hitting save.

**Step 2: Paste the below configuration in the mmu_hardware.cfg file**<br/><br/>
The below starter setup is for an 8 lane unit. To set up a lower lane count, paste the complete content below and change the below:

1. **num_gates: 8 -> to equal to the number of lanes you have**
2. **Delete the unnecessary tmc and stepper blocks**. For example if you have a 5 lane unit, delete `[tmc2209 stepper_mmu_gear_5]`, `[tmc2209 stepper_mmu_gear_6]`, `[tmc2209 stepper_mmu_gear_7]` blocks from the below.
3. **Delete the unnecessary pre_gate_switch_pin lines and post_gear_switch_pin lines**. For example for a 5 lane setup, remove `pre_gate_switch_pin_5`, `pre_gate_switch_pin_6`, `pre_gate_switch_pin_7`, `post_gear_switch_pin_5`, `post_gear_switch_pin_6`, `post_gear_switch_pin_7`
4. **Delete the unnecessary LED blocks**: add or remove `[neopixel mmuN_leds]` to match your number of lanes
5. ***Delete the unnecessary LED effect exit leds**: Add / remove `neopixel:mmuN_leds (x)` and `neopixel:mmuN_leds (x)` from the corresponding entry and exit sections in the `[mmu_leds unit0]` block.
6. Update your **toolhead sensors** definition to match your setup.

If you have more than 8 lanes, insert accordingly additional blocks, following the patterns illustrated in the full configuration file below.

> [!TIP]
> If during testing you see that the EMU stepper spins backwards, invert the dir_pin by adding a ! infront of it (!dir_pin).

```ini
# ----------------------------------------------------------------------------
# MMU Hardware config file ---------------------------------------------------
# ----------------------------------------------------------------------------
[mmu_machine]
num_gates: 8
mmu_vendor: EMU
mmu_version: 1.0

selector_type: VirtualSelector
variable_bowden_lengths: 1
variable_rotation_distances: 1
require_bowden_move: 1
filament_always_gripped: 1
has_bypass: 1

# Add your temperature and humidity sensors here for them to be visible in mainsail. One line per lane.
# Supported in HH vesion 3.42 and above.
environment_sensors:    temperature_sensor Lane_0,
                        temperature_sensor Lane_1,
                        temperature_sensor Lane_2,
                        temperature_sensor Lane_3,
                        temperature_sensor Lane_4,
                        temperature_sensor Lane_5,
                        temperature_sensor Lane_6,
                        temperature_sensor Lane_7

# ----------------------------------------------------------------------------
# Stepper definitions --------------------------------------------------------
# ----------------------------------------------------------------------------
# Lane 0 --------------------------
[tmc2209 stepper_mmu_gear]
uart_pin: mmu0:MMU_GEAR_UART
run_current: 0.8
hold_current: 0.10
interpolate: True
sense_resistor: 0.110
stealthchop_threshold: 0

[stepper_mmu_gear]
step_pin: mmu0:MMU_GEAR_STEP
dir_pin: mmu0:MMU_GEAR_DIR
enable_pin: !mmu0:MMU_GEAR_ENABLE
rotation_distance: 22.7574
gear_ratio: 1:1
microsteps: 4
full_steps_per_rotation: 200

# Lane 1 --------------------------
[tmc2209 stepper_mmu_gear_1]
uart_pin: mmu1:MMU_GEAR_UART

[stepper_mmu_gear_1]
step_pin: mmu1:MMU_GEAR_STEP
dir_pin: mmu1:MMU_GEAR_DIR
enable_pin: !mmu1:MMU_GEAR_ENABLE

# Lane 2 --------------------------
[tmc2209 stepper_mmu_gear_2]
uart_pin: mmu2:MMU_GEAR_UART

[stepper_mmu_gear_2]
step_pin: mmu2:MMU_GEAR_STEP
dir_pin: mmu2:MMU_GEAR_DIR
enable_pin: !mmu2:MMU_GEAR_ENABLE

# Lane 3 --------------------------
[tmc2209 stepper_mmu_gear_3]
uart_pin: mmu3:MMU_GEAR_UART

[stepper_mmu_gear_3]
step_pin: mmu3:MMU_GEAR_STEP
dir_pin: mmu3:MMU_GEAR_DIR
enable_pin: !mmu3:MMU_GEAR_ENABLE

# Lane 4 --------------------------
[tmc2209 stepper_mmu_gear_4]
uart_pin: mmu4:MMU_GEAR_UART

[stepper_mmu_gear_4]
step_pin: mmu4:MMU_GEAR_STEP
dir_pin: mmu4:MMU_GEAR_DIR
enable_pin: !mmu4:MMU_GEAR_ENABLE

# Lane 5 --------------------------
[tmc2209 stepper_mmu_gear_5]
uart_pin: mmu5:MMU_GEAR_UART

[stepper_mmu_gear_5]
step_pin: mmu5:MMU_GEAR_STEP
dir_pin: mmu5:MMU_GEAR_DIR
enable_pin: !mmu5:MMU_GEAR_ENABLE

# Lane 6 --------------------------
[tmc2209 stepper_mmu_gear_6]
uart_pin: mmu6:MMU_GEAR_UART

[stepper_mmu_gear_6]
step_pin: mmu6:MMU_GEAR_STEP
dir_pin: mmu6:MMU_GEAR_DIR
enable_pin: !mmu6:MMU_GEAR_ENABLE

# Lane 7 --------------------------
[tmc2209 stepper_mmu_gear_7]
uart_pin: mmu7:MMU_GEAR_UART

[stepper_mmu_gear_7]
step_pin: mmu7:MMU_GEAR_STEP
dir_pin: mmu7:MMU_GEAR_DIR
enable_pin: !mmu7:MMU_GEAR_ENABLE

# ----------------------------------------------------------------------------
# Sensors definitions --------------------------------------------------------
# ----------------------------------------------------------------------------

[mmu_sensors]
pre_gate_switch_pin_0: ^mmu0:MMU_PRE_GATE
pre_gate_switch_pin_1: ^mmu1:MMU_PRE_GATE
pre_gate_switch_pin_2: ^mmu2:MMU_PRE_GATE
pre_gate_switch_pin_3: ^mmu3:MMU_PRE_GATE
pre_gate_switch_pin_4: ^mmu4:MMU_PRE_GATE
pre_gate_switch_pin_5: ^mmu5:MMU_PRE_GATE
pre_gate_switch_pin_6: ^mmu6:MMU_PRE_GATE
pre_gate_switch_pin_7: ^mmu7:MMU_PRE_GATE

post_gear_switch_pin_0: ^mmu0:MMU_POST_GEAR
post_gear_switch_pin_1: ^mmu1:MMU_POST_GEAR
post_gear_switch_pin_2: ^mmu2:MMU_POST_GEAR
post_gear_switch_pin_3: ^mmu3:MMU_POST_GEAR
post_gear_switch_pin_4: ^mmu4:MMU_POST_GEAR
post_gear_switch_pin_5: ^mmu5:MMU_POST_GEAR
post_gear_switch_pin_6: ^mmu6:MMU_POST_GEAR
post_gear_switch_pin_7: ^mmu7:MMU_POST_GEAR

# if you have a toolhead sensors, uncomment and insert the definitions here
# extruder_switch_pin: ^TOOLHEAD_CAN: PB6
# toolhead_switch_pin: ^TOOLHEAD_CAN: PB5

# Section below if using the dual switch version of the EMU Sync. Uncomment the below
# sync_feedback_tension_pin: ^mmu0:MMU_TENSION         # Compression is when you pull the bowden tubes (entry/exit) away from each other. Tension when you push the tubes together.
# sync_feedback_compression_pin: ^mmu0:MMU_COMPRESSION

# Section below if using the Proportional (PSF) version of the EMU Sync.
# Comment out/delete the dual switch section above and uncomment the section below to use.
# Dont forget to run the calibration routine (MMU_CALIBRATE_PSENSOR) and
# update the sync_feedback_analog_max_compression, sync_feedback_analog_max_tension and sync_feedback_analog_neutral_point accordingly.

# sync_feedback_analog_pin: mmu0:MMU_TH
# sync_feedback_analog_max_compression: 0.9435
# sync_feedback_analog_max_tension:     0.0982
# sync_feedback_analog_neutral_point:   0.5275

# ----------------------------------------------------------------------------
# MMU NEOPIXEL LED SUPPORT EBB42/36 ------------------------------------------
# Delete or comment out if not using an EBB42/36 -----------------------------
# Below sample configuration is shown for printed eject button ---------------
# Update as per instructions for PCB LED eject button ------------------------
# ----------------------------------------------------------------------------

[neopixel _mmu0_leds] # one block per lane (Lane 0)
pin: mmu0:MMU_NEOPIXEL
chain_count: 2 # one for the box and one for the eject button. Set to 5 for the LED PCB
color_order: GRBW

[neopixel _mmu1_leds] # one block per lane (Lane 1)
pin: mmu1:MMU_NEOPIXEL
chain_count: 2
color_order: GRBW

[neopixel _mmu2_leds] # one block per lane (Lane 2)
pin: mmu2:MMU_NEOPIXEL
chain_count: 2
color_order: GRBW

[neopixel _mmu3_leds] # one block per lane (Lane 3)
pin: mmu3:MMU_NEOPIXEL
chain_count: 2
color_order: GRBW

[neopixel _mmu4_leds] # one block per lane (Lane 4)
pin: mmu4:MMU_NEOPIXEL
chain_count: 2
color_order: GRBW

[neopixel _mmu5_leds] # one block per lane (Lane 5)
pin: mmu5:MMU_NEOPIXEL
chain_count: 2
color_order: GRBW

[neopixel _mmu6_leds] # one block per lane (Lane 6)
pin: mmu6:MMU_NEOPIXEL
chain_count: 2
color_order: GRBW

[neopixel _mmu7_leds] # one block per lane (Lane 7)
pin: mmu7:MMU_NEOPIXEL
chain_count: 2
color_order: GRBW

[mmu_leds unit0]
exit_leds:
  neopixel:_mmu0_leds (1) # add/remove to match number of lanes. Set to (1,2,3,4) for the LED PCB
  neopixel:_mmu1_leds (1)
  neopixel:_mmu2_leds (1)
  neopixel:_mmu3_leds (1)
  neopixel:_mmu4_leds (1)
  neopixel:_mmu5_leds (1)
  neopixel:_mmu6_leds (1)
  neopixel:_mmu7_leds (1)
entry_leds:
  neopixel:_mmu0_leds (2) # add/remove to match number of lanes. Set to (5) for the LED PCB
  neopixel:_mmu1_leds (2)
  neopixel:_mmu2_leds (2)
  neopixel:_mmu3_leds (2)
  neopixel:_mmu4_leds (2)
  neopixel:_mmu5_leds (2)
  neopixel:_mmu6_leds (2)
  neopixel:_mmu7_leds (2)
frame_rate: 15

# ----------------------------------------------------------------------------
# MMU NEOPIXEL LED SUPPORT Solo Lane Board (SLB) -----------------------------
# Delete or comment out if not using an SLB ----------------------------------
# Below sample configuration is shown for the PCB LED eject button -----------
# Update as per instructions for printed eject button  -----------------------
# ----------------------------------------------------------------------------

[neopixel _mmu0_leds_box] # one block per lane (Lane 1)
pin: mmu0:MMU_NEOPIXEL_BOX
chain_count: 1   # Always 1 LED for the box
color_order: GRBW

[neopixel _mmu0_leds_button] # one block per lane (Lane 1)
pin: mmu0:MMU_NEOPIXEL_BUTTON
chain_count: 4   # Set to 1 if using Neopixel eject button. Set to 4 if using LED PCB
color_order: GRBW

[neopixel _mmu1_leds_box] # one block per lane (Lane 2)
pin: mmu1:MMU_NEOPIXEL_BOX
chain_count: 1
color_order: GRBW

[neopixel _mmu1_leds_button] # one block per lane (Lane 2)
pin: mmu1:MMU_NEOPIXEL_BUTTON
chain_count: 4
color_order: GRBW

[neopixel _mmu2_leds_box] # one block per lane (Lane 3)
pin: mmu2:MMU_NEOPIXEL_BOX
chain_count: 1
color_order: GRBW

[neopixel _mmu2_leds_button] # one block per lane (Lane 3)
pin: mmu2:MMU_NEOPIXEL_BUTTON
chain_count: 4
color_order: GRBW

[neopixel _mmu3_leds_box] # one block per lane (Lane 4)
pin: mmu3:MMU_NEOPIXEL_BOX
chain_count: 1
color_order: GRBW

[neopixel _mmu3_leds_button] # one block per lane (Lane 4)
pin: mmu3:MMU_NEOPIXEL_BUTTON
chain_count: 4
color_order: GRBW

[neopixel _mmu4_leds_box] # one block per lane (Lane 5)
pin: mmu4:MMU_NEOPIXEL_BOX
chain_count: 1
color_order: GRBW

[neopixel _mmu4_leds_button] # one block per lane (Lane 5)
pin: mmu4:MMU_NEOPIXEL_BUTTON
chain_count: 4
color_order: GRBW

[neopixel _mmu5_leds_box] # one block per lane (Lane 6)
pin: mmu5:MMU_NEOPIXEL_BOX
chain_count: 1
color_order: GRBW

[neopixel _mmu5_leds_button] # one block per lane (Lane 6)
pin: mmu5:MMU_NEOPIXEL_BUTTON
chain_count: 4
color_order: GRBW

[neopixel _mmu6_leds_box] # one block per lane (Lane 7)
pin: mmu6:MMU_NEOPIXEL_BOX
chain_count: 1
color_order: GRBW

[neopixel _mmu6_leds_button] # one block per lane (Lane 7)
pin: mmu6:MMU_NEOPIXEL_BUTTON
chain_count: 4
color_order: GRBW

[neopixel _mmu7_leds_box] # one block per lane (Lane 8)
pin: mmu7:MMU_NEOPIXEL_BOX
chain_count: 1
color_order: GRBW

[neopixel _mmu7_leds_button] # one block per lane (Lane 8)
pin: mmu7:MMU_NEOPIXEL_BUTTON
chain_count: 4
color_order: GRBW

[mmu_leds unit0]
exit_leds:
  neopixel:_mmu0_leds_button (1,2,3,4)
  neopixel:_mmu1_leds_button (1,2,3,4)
  neopixel:_mmu2_leds_button (1,2,3,4)
  neopixel:_mmu3_leds_button (1,2,3,4)
  neopixel:_mmu4_leds_button (1,2,3,4)
  neopixel:_mmu5_leds_button (1,2,3,4)
  neopixel:_mmu6_leds_button (1,2,3,4)
  neopixel:_mmu7_leds_button (1,2,3,4)
  neopixel:_mmu8_leds_button (1,2,3,4)
entry_leds:
  neopixel:_mmu0_leds_box (1)
  neopixel:_mmu1_leds_box (1)
  neopixel:_mmu2_leds_box (1)
  neopixel:_mmu3_leds_box (1)
  neopixel:_mmu4_leds_box (1)
  neopixel:_mmu5_leds_box (1)
  neopixel:_mmu6_leds_box (1)
  neopixel:_mmu7_leds_box (1)
frame_rate: 15

# ----------------------------------------------------------------------------
# MMU EFFECTS - EBB42,36 and Solo Lane Board ---------------------------------
# ----------------------------------------------------------------------------

enabled: True                           # LEDs are enabled at startup
animation: True                         # Use led-animation-effects
exit_effect: gate_status                # gate_status in the eject buttons
entry_effect: filament_color            # filament_color in the dry box LED
status_effect: off                      # no status LED is on the unit
logo_effect: (0, 0, 0)                  # no Logo LED is on the unit
white_light: (1, 1, 1)                  # RGB color for static white light
black_light: (1, 1, 1)                  # RGB color used to represent "black" filament
empty_light: (0.0, 0.0, 0.0)            # Empty gate has eject button "off"

effect_loading:            mmu_clockwise_fast, (0, 0, 0.4)
effect_loading_extruder:   mmu_clockwise_slow, (0, 0, 1)
effect_unloading:          mmu_anticlock_fast, (0, 0, 0.4)
effect_unloading_extruder: mmu_anticlock_slow, (0, 0, 1)
effect_heating:            mmu_breathing_red,       (0.3, 0, 0)
effect_selecting:          mmu_white_fast,          (0.2, 0.2, 0.2)
effect_checking:           mmu_white_fast,          (0.8, 0.8, 0.8)
effect_initialized:        mmu_rainbow,             (0.5, 0.2, 0)
effect_error:              mmu_strobe,              (1, 0, 0)
effect_complete:           mmu_sparkle,             (0.3, 0.3, 0.3)
effect_gate_selected:      mmu_static_blue,         (0, 0, 1)
effect_gate_available:     mmu_static_white_dim,    (0.3, 0.3, 0.3)
effect_gate_available_sel: mmu_static_white,        (0.75, 0.75, 0.75)
effect_gate_unknown:       mmu_static_orange,       (0.5, 0.2, 0)
effect_gate_unknown_sel:   mmu_ready_orange ,       (0.75, 0.3, 0)
effect_gate_empty:         mmu_static_black,        (0, 0, 0)
effect_gate_empty_sel:     mmu_static_red,           (0.2, 0, 0)

```

### Update mmu/addons/mmu_eject_buttons_hw.cfg

**Step 1: Clear the mmu_eject_buttons_hw.cfg file.** <br/><br/>
Start by completely deleting the content of that file and hitting save.

**Step 2: Paste the below configuration in the mmu_eject_buttons_hw.cfg file**<br/><br/>
The below starter setup is for an 8 lane unit. To set up a lower lane count, paste the complete content below and delete the corresponding `[gcode_button mmu_eject_button_N]` sections. If you have more than 8 lanes, add more blocks following the patterns below.

```ini
# ----------------------------------------------------------------------------
# ------- Eject Buttons. Notice the (!) in the pin definition! ---------------
# ----------------------------------------------------------------------------
[gcode_button mmu_eject_button_0]
pin: ^!mmu0:EJECT_BUTTON
press_gcode: _MMU_EJECT_BUTTON GATE=0

[gcode_button mmu_eject_button_1]
pin: ^!mmu1:EJECT_BUTTON
press_gcode: _MMU_EJECT_BUTTON GATE=1

[gcode_button mmu_eject_button_2]
pin: ^!mmu2:EJECT_BUTTON
press_gcode: _MMU_EJECT_BUTTON GATE=2

[gcode_button mmu_eject_button_3]
pin: ^!mmu3:EJECT_BUTTON
press_gcode: _MMU_EJECT_BUTTON GATE=3

[gcode_button mmu_eject_button_4]
pin: ^!mmu4:EJECT_BUTTON
press_gcode: _MMU_EJECT_BUTTON GATE=4

[gcode_button mmu_eject_button_5]
pin: ^!mmu5:EJECT_BUTTON
press_gcode: _MMU_EJECT_BUTTON GATE=5

[gcode_button mmu_eject_button_6]
pin: ^!mmu6:EJECT_BUTTON
press_gcode: _MMU_EJECT_BUTTON GATE=6

[gcode_button mmu_eject_button_7]
pin: ^!mmu7:EJECT_BUTTON
press_gcode: _MMU_EJECT_BUTTON GATE=7
```

### Upload the emu_macros.cfg file and reference it in your printer.cfg

The [linked file here](https://github.com/DW-Tas/EMU/tree/main/macros) contains a set of configurations and definitions that are required for EMU to function. In addition, it contains a fan auto control macro, to minimize noise and ensure adequate unit cooling.

Upload that file in your klipper environment and add the below line to include it in your printer.cfg file:
`[include emu_macros.cfg]`

That file contains the **BME temperature and humidity sensor definitions** as below. It is set up for an 8 lane unit, so if you have less lanes or not using the BME sensor, delete the corresponding blocks from the file.

```ini
# ----------------------------------------------------------------------------
# Temperature and Humidity Sensors - BME & EBB42/36 --------------------------
# ----------------------------------------------------------------------------
[temperature_sensor Lane_N]
sensor_type: BME280
i2c_address: 118
i2c_mcu: mmuN  # mmu0=First lane, mmu1=second lane etc.
i2c_software_scl_pin: mmuN:PB3 # mmu0=First lane, mmu1=second lane etc.
i2c_software_sda_pin: mmuN:PB4 # mmu0=First lane, mmu1=second lane etc.

# ----------------------------------------------------------------------------
# Temperature and Humidity Sensors - BME & Solo Lane Board (SLB) -------------
# ----------------------------------------------------------------------------
[temperature_sensor Lane_N]
sensor_type: BME280
i2c_address: 118
i2c_mcu: mmuN  # mmu0=First lane, mmu1=second lane etc.
i2c_software_scl_pin: mmuN:PB10 # mmu0=First lane, mmu1=second lane etc.
i2c_software_sda_pin: mmuN:PB11 # mmu0=First lane, mmu1=second lane etc.

```

If you're using the BOM **AHT20 temperature and humidity sensors**, use the below configuration block instead.

```ini
# ----------------------------------------------------------------------------
# Temperature and Humidity Sensors - AHT20 & EBB42/36 ------------------------
# ----------------------------------------------------------------------------
[temperature_sensor Lane_N]
sensor_type: AHT2X
aht10_report_time: 60
i2c_address: 56
i2c_mcu: mmuN # mmu0=First lane, mmu1=second lane etc.
i2c_software_scl_pin: mmuN:PB3 # mmu0=First lane, mmu1=second lane etc.
i2c_software_sda_pin: mmuN:PB4 # mmu0=First lane, mmu1=second lane etc.

# ----------------------------------------------------------------------------
# Temperature and Humidity Sensors - BME & Solo Lane Board (SLB) -------------
# ----------------------------------------------------------------------------
[temperature_sensor Lane_N]
sensor_type: AHT2X
aht10_report_time: 60
i2c_address: 56
i2c_mcu: mmuN # mmu0=First lane, mmu1=second lane etc.
i2c_software_scl_pin: mmuN:PB10 # mmu0=First lane, mmu1=second lane etc.
i2c_software_sda_pin: mmuN:PB11 # mmu0=First lane, mmu1=second lane etc.
```

It also contains the definition of the onboard temperature sensors used to control the unit fans. Similarly, it is set up for an 8 lane unit, so if you have less lanes, delete the corresponding blocks from the file.

```ini
[temperature_sensor _Lane_N_onboard]
sensor_type: temperature_mcu
sensor_mcu: mmu0 # mmu0=First lane, mmu1=second lane etc.
min_temp: 0
max_temp: 130
```

In addition, it contains the fan definitions for the unit as below. Similarly, it is set up for an 8 lane unit, so if you have less lanes, delete the corresponding blocks from the file.

```ini
[fan_generic _emu_fan_N]
pin: mmu0:MMU_FAN # mmu0=First lane, mmu1=second lane etc.
max_power: 1
kick_start_time: 0.5
```

Finally it contains the fan control macro that controls the fans on a by-lane basis. In the variable_sensors add the names of the **\_Lane_N_onboard temperature sensors**, separated by a comma. In the variable_fans add the names of the **base unit fans**, separated by a comma.

> [!NOTE]
> Prefixing the fans and board temperature sensors with a _ will hide them from the Mainsail UI, which is helpful to reduce clutter once you have your setup tuned and validated.

> [!IMPORTANT]
> The length of these two lists must match and correspond to each other (ie lane 0 fan and lane 0 onboard temp sensor must be first on the list etc).
> Make sure you include the **onboard temperature sensors in the fan control macro, not the BME sensors!**

Finally you can set the temperature where the fans turn on and off. By default, they are set to turn on at 39C and turn off at 37C.

```ini
[gcode_macro MMU_FAN_CFG]
description: Holds configuration/state for multi fan controller.
variable_on_temp: 39.0
variable_off_temp: 37.0
variable_poll_s: 5.0
variable_enabled: True
variable_forced: -1                 # -1=AUTO, 0=all OFF, 1=all ON (global)
variable_sensors: "_Lane_0_onboard,_Lane_1_onboard,_Lane_2_onboard,_Lane_3_onboard,_Lane_4_onboard,_Lane_5_onboard,_Lane_6_onboard,_Lane_7_onboard"   # Comma-separated temperature_sensor names
variable_fans:    "_emu_fan_0,_emu_fan_1,_emu_fan_2,_emu_fan_3,_emu_fan_4,_emu_fan_5,_emu_fan_6,_emu_fan_7"  # Comma-separated fan_generic names
variable_warned_len_mismatch: False # internal: warn once per enable
gcode:
```

That file also contains some bespoke LED effects for the EMU, which are used earlier in the LED setup section.

### Save, restart and confirm lanes are visible

Once all of the above steps are completed hit save and restart klipper. The MMU hardware should now all be set up and all your lanes visible in the machine panel as below:

<p align="center">
  Installer screen
</p>

## Configuring Happy Hare parameters

Now that the hardware is set up and visible to klipper, the next step is to configure the Happy Hare software to match the EMU capabilities and general Type B MMU good practice. That configuration will be predominately done in the mmu/base/mmu_parameters.cfg file. The indicated configuration below is geared towards reliability of feeding vs. filament swap speed. Use that as a starting point and tune to your liking once the unit is fully configured and operational.

### Setting up the EMU software parameters in mmu/base/mmu_parameters.cfg

Unlike the hardware setup files, do not delete the content of this file. We will be making targeted changes to match the EMU capabilities as validated through our testing.

**MMU Hardware Limits:** The EMU can operate up to a maximum of 500mm/sec feeding velocity and 400mm/sec2 acceleration. Adjust the maximum hardware limits as below.</br>

```ini
gear_max_velocity: 500
gear_max_accel: 400
```

**Logging:** Reduce log verbosity to reduce SD Card wear and system load</br></br>

```ini
log_level: 1
log_file_level: 1
log_statistics: 0
log_visual: 1
log_startup_status: 1
log_m117_messages: 1
```

**Speeds:** Our objective is reliability with operation. While the EMU can operate at 500mm/sec feeding, any snag in the filament path risks the lane stepper skipping steps. As such, it is recommended that conservative values are used in the speed set up, and tune up from there.</br>

```ini
gear_from_spool_speed: 250
gear_from_spool_accel: 120
gear_from_buffer_speed: 250
gear_from_buffer_accel: 120
gear_unload_speed: 250
gear_unload_accel: 120

gear_short_move_speed: 80
gear_short_move_accel: 80
gear_short_move_threshold: 100
gear_homing_speed: 80

extruder_load_speed: 16
extruder_unload_speed: 16
extruder_sync_load_speed: 16
extruder_sync_unload_speed: 20
extruder_homing_speed: 16

macro_toolhead_max_accel: 0
macro_toolhead_min_cruise_ratio: 0.5
```

**Gate load:** The EMU uses the post stepper (gear) switch sensor as the filament homing point for the lanes. That means that when swapping colors, the filament will retract all the way into the EMU dry box. This has three benefits which maximise flexibility in lane / base unit arrangements and reliability in feeding filament:

1. The filament is kept as dry as possible as it is now fully in the dry box. This results in lower probability of the filament snapping in the lane stepper gear due to it absorbing humidity from the environment.
2. There is no need for a sensor at the combiner, simplifying wiring setup and configuration.
3. You can expand to as many lanes as you want with any combination of passive combiners to bring the lane bowden tubes together to one that feeds the toolhead.

The downside is that the full bowden length needs to be traversed when loading, resulting in slightly longer loading times (however that is almost insignificant) and that the bowden length for each lane needs to be calibrated before first use (this is an automated process described later in this section).

In addition, conservative homing max and preload homing max value have been selected, to allow the user time to load the filament and ensure it is gripped by the EMU lane stepper.

It is therefore recommended to use the below values as is and do not modify unless trying to troubleshoot a specific issue.</br>

```ini
gate_homing_endstop: mmu_gear
gate_homing_max: 600
gate_preload_homing_max: 600
gate_preload_parking_distance: 1
gate_unload_buffer: 200
gate_parking_distance: 1          # park the filament 1mm before the stepper exit switch. Do not increase this value beyond this as you are then risking the filament walking past the stepper gears.
gate_autoload: 1
gate_final_eject_distance: 100
```

**Bowden load:** As the EMU can accomodate long bowden tubes feeding to the printer, the bowden_homing_max is increased to allow Happy Hare to feed a longer run.

In addition the correction and unload test moves are disabled as the encoder is not fitted in the base setup. From experience, encoders tend to accumulate dust after a few thousand swap cycles requiring ongoing maintenance. In addition they materially elevate the noise profile of the unit and add a point of "filament impact" in the bowden loading path.</br>

```ini
bowden_homing_max: 3000 # if the EMU lane to toolhead distance is larger than 3 meters, increase this value.

bowden_apply_correction: 0
bowden_allowable_load_delta: 10.0

bowden_pre_unload_test: 0
bowden_pre_unload_error_tolerance: 60
```

**Extruder homing:** The below values are tuned to improve overall feeding reliability. The extruder homing max value has been increased, allowing for slight slippage during the bowden load. In addition, the homing buffer has been increased, reducing the bowden fast load speed 30mm before the filament arrives at the toolhead. This reduces possibility of filament impacting the gears.</br>

> [!IMPORTANT]
> Depending on your toolhead of choice you may need to adjust the below extruder_homing_endstop parameter. If your toolhead has an entry sensor, set this to extruder_homing_endstop: extruder. If it doesnt, and you are using the EMU Sync with dual switches, set this value to extruder_homing_endstop: filament_compression. Finally if you're using the PSF and your toolhead doesnt have an entry sensor set this value to extruder_homing_endstop: proportional

```ini
extruder_homing_max: 400   # Larger than the default HH value. This allows for homing to complete even if the filament skips steps during the load/
extruder_homing_endstop: extruder # or proportional or filament_compression. See note above.
extruder_homing_buffer: 30
extruder_collision_homing_current: 100

extruder_force_homing: 0
```

**Toolhead Load:** This section needs to be populated following toolhead dimension calibration. Starter values from the community are available here: <https://link.3dcoded.xyz/tipconfigs/> .

## Manual sensorless toolhead calibration

If your toolhead does **not** have a filament sensor and you need to derive the Happy Hare toolhead dimensions (`toolhead_extruder_to_nozzle`, `toolhead_entry_to_extruder`, `toolhead_residual_filament`, plus the cutter parameters) by hand, follow the dedicated guide:
→ [Manual Sensorless Toolhead Calibration for Happy Hare](/docs/software_setup/07-manual-toolhead-calibration.md)

## Manual two-sensor toolhead calibration

If your toolhead has **two filament sensors** (a pre-extruder entry sensor and a post-extruder toolhead sensor) and you need to derive the Happy Hare toolhead dimensions (`toolhead_extruder_to_nozzle`, `toolhead_entry_to_extruder`, `toolhead_sensor_to_nozzle`, `toolhead_residual_filament`, plus the cutter parameters) by hand, follow the dedicated guide:
→ [Manual Toolhead Calibration with Two Sensors for Happy Hare](/docs/software_setup/08-manual_toolhead_calibration_two_sensors.md)

In addition, the below settings have been adjusted to allow more tolerance in case of the extruder delaying grabbing the filament, which improves feeding reliability and allows for more "flex" in a slightly miss-tuned setup</br>

```ini
toolhead_homing_max: 250   # Increased from default of 40, to allow more tolerance in the extruder not grabbing the filament immediately.
toolhead_unload_safety_margin: 50 # Increased from the default of 10, to ensure filament is for sure clear of the extruder during unload.
toolhead_post_load_tighten: 0  # this is ignored as EMU is a Type B MMU - set to 0
toolhead_post_load_tension_adjust: 1 # Adjust tension post load to attemt to centre the sync feedback sensor.
toolhead_entry_tension_test: 1  # confirm load has occurred using the sync sensor, if toolhead sensor is not present.
```

**Tip Forming:** A toolhead cutter is highly recommended. Venture into tip forming at your own risk!</br>

```ini
force_form_tip_standalone: 1    # Always standalone tip forming (TURN SLICER OFF!)
form_tip_macro: _MMU_CUT_TIP
extruder_form_tip_current: 130    # Bump up extruder current during tip forming. Helps ensure no skipped steps on the extruder if cutting is not 100% clean
slicer_tip_park_pos: 0         # This specifies the position of filament in extruder after slicer completes tip forming. (TURN SLICER TIP FORMING OFF!)
```

**Purging:** If you have the blobifier set up, enable it here. For a baseline, starter setup, the below is recommended. Setting up the blobifier is recommended to be done after this setup is complete and your first test print is completed successfully.</br>

```ini
force_purge_standalone: 0   # Use slicer purging (purge block) - set to 1 for blobifier
purge_macro:                # Replace this with BLOBIFIER when set up. Leave empty if not using the blobifier.
extruder_purge_current: 100  # leave this unchanged. If the extruder is skipping during purging with the blobifier you are most likely exceeding your hotend flow limit.
```

**Motor sync:** Setup sync feedback sensor (EMUSync) here. Adjust the below values leaving the rest unchanged.</br>

```ini
sync_gear_current: 55       # 55% EMU stepper current during printing -> ~0.4-0.45A when printing. Higher than 0.5A can cause PLA to clog the EMU stepper in hot environments.
sync_feedback_enabled: 1      # Enable EMU Sync sync feedback sensor
sync_feedback_buffer_range: 10  # EMU Sync switch to switch distance in mm. PFS is 16mm
sync_feedback_buffer_maxrange: 25 # EMU Sync max travel. PFS is 16mm
```

**Filament Management:** Disable clog detection (as the encoder is not fitted to the unit) and enable endless spool (automated failover to the next available spool as defined in the gate map, administered via the Mainsail UI or Klipperscreen).</br>

```ini
enable_clog_detection: 0
enable_endless_spool: 1       # enable endless spool
endless_spool_on_load: 0
endless_spool_eject_gate: -1  # Eject filament in the current gate
```

Here you can also configure spoolman filament management (highly recommended - instructions here:<https://github.com/moggieuk/Happy-Hare/wiki/Spoolman-Support>). </br></br>

**Calibration:**
The Happy Hare software together with the advanced sensors the EMU utilises enable a number of auto-calibration features that simplify initial start up. These features remove the need for any calibration of the unit.

To enable the auto calibration routines set the below parameters in the mmu_parameters.cfg file. These auto calibrations have the below pre-requisites:

1. You are using a **toolhead with an entry sensor**, ie a switch based sensor is present before the extruder and you have enabled `extruder_homing_endstop: extruder` in mmu_parameters.cfg
2. **OR** you are using the **EMU Sync with dual switches** and you have enabled `extruder_homing_endstop: filament_compression` in mmu_parameters.cfg
3. **OR** you are using the **EMU Sync with PSF** and [the newly developed code here](https://github.com/moggieuk/Happy-Hare/pull/936) and you have enabled `extruder_homing_endstop: proportional` in mmu_parameters.cfg

If you are not satisfied with the automatically calibrated values, [the above calibrations can also be executed manually as described in this page](/docs/software_setup/legacy_hhv3/03-calibration-and-startup.md).

```ini
autocal_bowden_length: 1 # Disable automated bowden length calibration
autotune_bowden_length: 0 # Disable automated bowden length tuning
skip_cal_rotation_distance: 1 # Require gate rotation distance calibration
autotune_rotation_distance: 0 # Disable automated gate calibration/tuning.
skip_cal_encoder: 0  # Encoder not fitted
autotune_encoder: 0  # Encoder not fitted
```

**Misc:** Minor options tuning and instructing Happy Hare that a filamentalist rewinder is used instead of a buffer </br>

```ini
timeout_pause: 86400      # Idle time out in seconds. Set to 24 hours, to allow you to react and fix a pause if a swap issue materialises.
disable_heater: 60          # Disable the hotend heater 60 seconds after an error is detected to reduce oozing.
default_extruder_temp: 230     # Default temperature for performing swaps and forming tips when not in print (overridden by gate map). 230C is a good all around temperature for most material types.
extruder_temp_variance: 30     # When waiting for extruder temperature this is the +/- permissible variance in degrees (>= 1).

startup_home_if_unloaded: 0     # 0 = do nothing
startup_reset_ttg_map: 0     #  0 = do nothing
show_error_dialog: 0      # 0 = show error in console only. No mainsail pop-up
preload_attempts: 5          # How many "grabbing" attempts are made to pick up the filament with preload feature
strict_filament_recovery: 0     # If enabled with MMU with toolhead sensor, this will cause filament position recovery to
                                # perform extra moves to look for filament trapped in the space after extruder but before sensor
                                # This is largely uncessary but can be enabled if your toolhead setup is not particularly reliable.
filament_recovery_on_pause: 1 # Run a quick check to determine current filament position on pause/error.
retry_tool_change_on_error: 1 # Automatically retry a failed tool change. While this may mask a unit issue, we are aiming for relability during print.
bypass_autoload: 1          # If extruder sensor fitted, this controls the automatic loading of extruder for bypass operation
has_filament_buffer: 0          # We are using a Filamentalist so no separate filament buffer is installed
#
# Advanced options. Don't mess unless you fully understand. Read documentation.
#
encoder_move_validation: 0      # ADVANCED: 1 = Normally Encoder validates move distances are within given tolerance
                                 #           0 = Validation is disabled (eliminates slight pause between moves but less safe)
print_start_detection: 1      # ADVANCED: Enabled for Happy Hare to automatically detect start and end of print and call
                                 # ADVANCED: MMU_PRINT_START and MMU_PRINT_END automatically. Harmless to leave enabled but can disable
                                 #           if you think it is causing problems and known START/END is covered in your macros
extruder: extruder           # ADVANCED: Name of the toolhead extruder that MMU is using
gcode_load_sequence: 0       # VERY ADVANCED: Gcode loading sequence 1=enabled, 0=internal logic (default)
gcode_unload_sequence: 0      # VERY ADVANCED: Gcode unloading sequence, 1=enabled, 0=internal logic (default)
```

**Klipper:** Enable klipper timer too close (TTC) mitigations.</br>

```ini
update_trsync: 1      # 1 = Increase TRSYNC_TIMEOUT, 0 = Leave the klipper default
canbus_comms_retries: 3  # Number of retries. Recommend the default of 3.
update_bit_max_time: 1  # 1 = Increase BIT_MAX_TIME, 0 = Leave the klipper default
update_aht10_commands: 0 # BTT ViViD specific setting. Leave at 0.
```

### Setting up the EMU software parameters in mmu/base/mmu_macro_vars.cfg

Unlike the hardware setup files, do not delete the content of this file. The below are some common settings that I have found useful to change from default. However, the **detailed guide on Happy hare must be followed to set up your cut tip macro and to configure the system for your specific printer setup**. For more read here: <https://github.com/moggieuk/Happy-Hare/wiki/Configuring-mmu_macro_vars.cfg>

> [!WARNING]
> **WARNING: DO NOT RUN A PRINT WITHOUT CONFIGURING THE ABOVE.** The stock cut tip macro will most likely not work for your setup and you will crash the hotend on the cutter.

```ini
variable_min_toolchange_z       : 15.0 # Be safe and dont scratch the bed
variable_park_travel_speed      : 450  # Travel a bit faster to avoid stringing
```

## Configuring PSF and Flowguard

EMU and Happy Hare supports using a [proportional sync feedback sensor](<https://github.com/DW-Tas/EMU/tree/main/STL/Tension-compression-sensor/Proportional%20Sync%20Feedback%20(PSF)%20Version>) to accurately measure filament tension in the bowden tube. This is used in place of and instead of the dual switch EMUSync. The sensor [is available to purchase from Aliexpress](https://www.aliexpress.com/item/1005010470743517.html).

The proportional sensor offers the below key advantages:

1. Real time tension/compression monitoring in the bowden tube
2. Precise synchronisation between the extruder and EMU steppers
3. Real time detection of both clogs and tangles

### PSF Configuration

The sensor is plugged in [as per the wiring diagram](https://github.com/DW-Tas/EMU/tree/main/docs/assembly_wiring#wiring-instructions-and-diagrams) - ground and signal plug into the EBB thermistor port and 5V to any unused 5V pins on the EBB.

**Step 1:** Comment out or delete the below section in the mmu_hardware.cfg file:

```ini
# sync_feedback_tension_pin: ^mmu0:MMU_TENSION         # Compression is when you pull the bowden tubes (entry/exit) away from each other. Tension when you push the tubes together.
# sync_feedback_compression_pin: ^mmu0:MMU_COMPRESSION
```

**Step 2:** Uncomment or add the below section right below in the mmu_hardware.cfg file:

```ini
# Section below if using the Proportional (PSF) version of the EMU Sync. Run the calibration routine (MMU_CALIBRATE_PSENSOR) and
# update the sync_feedback_analog_max_compression, sync_feedback_analog_max_tension and sync_feedback_analog_neutral_point accordingly.
# Comment out/delete the dual switch section above and uncomment the section below to use.
sync_feedback_analog_pin: mmu0:MMU_TH
sync_feedback_analog_max_compression: 0.9
sync_feedback_analog_max_tension:     0.1
sync_feedback_analog_neutral_point:   0.5
```

**Step 3:** Restart and test the sensor.

1. Pull the bowden tube and expand the EMUSync PSF sensor. While holding in the expanded position run the below macro in the printer console: `MMU_QUERY_PSENSOR`.
2. Compress the sensor by pushing the ends together and run the same macro again. Record both values.

> [!IMPORTANT]
> You should see a **max raw value** greater than ~0.9 and a **min raw value** or less than ~0.1. If the values do not change when expanding and compressing the sensor recheck your wiring!

> [!IMPORTANT]
> **If your sensor reads as 1.0 when filament is unloaded** the magnet is positioned in reverse! **Flip the magnet or swap the sync_feedback_analog_max_compression to be equal to 0.1 and sync_feedback_analog_max_tension to equal to 0.9**.

**Step 4:** Set the EMUSync dimensions in the mmu_parameters.cfg file as below. Save and restart.

```ini
sync_gear_current: 55       # 55% EMU stepper current during printing -> ~0.4-0.45A when printing. Higher than 0.5A can cause PLA to clog the EMU stepper in hot environments.

sync_feedback_enabled: 1    # Enable sync feedback
sync_feedback_buffer_range: 16  # Travel in "buffer" between compression/tension or one sensor and end
sync_feedback_buffer_maxrange: 16 # Absolute maximum end-to-end travel (mm) provided by buffer
sync_feedback_speed_multiplier: 5 # % "twolevel" gear speed delta to keep filament neutral in buffer
sync_feedback_boost_multiplier: 3 # % "twolevel" extra gear speed boost for finding initial neutral position
sync_feedback_extrude_threshold: 5 # Extruder movement (mm) for updates
```

**Step 5:** Calibrate the sensor.

1. Load filament from any lane to the toolhead using a Tx (T0,T1 etc) command.
2. In the console run `MMU_CALIBRATE_PSENSOR`
3. Note down the produced values

> [!IMPORTANT]
> If the max and min values differ significantly (>0.1) from the min and max raw values above, your calibration has failed due to excess bowden tube slack or because the sensor is getting jammed due to excess friction. Validate that the sensor moves freely and run the calibration command again. If you have a long bowden tube you may need to run MMU_CALIBRATE_PSENSOR MOVE=40 to take up the bowden slack`

The produced values should look like the below:

```ini
sync_feedback_analog_max_compression: 0.9435
sync_feedback_analog_max_tension:     0.0982
sync_feedback_analog_neutral_point:   0.5275
```

Update the corresponding values in the mmu_hardware.cfg file, save and restart.

**Step 6:** Configure flowguard (clog/tangle detection) <br/>
Edit the mmu_parameters.cfg file and amend the values below to match the suggested configuration.

```ini
flowguard_enabled: 1
flowguard_max_relief: 2
flowguard_encoder_mode: 0
```

Save and restart.

**Step 7:** After you've completed setup (slicer setup) you can now start a print and test the sensor

1. Start a print and monitor the flowguard value in the MMU panel. It should remain close to the neutral (0) threshold
2. Expand the sensor manually - flowguard should trigger a pause. Let go, and click resume. The print should continue uninterrupted.



### EMUSync PSF insights

You can use the sync sensor to visualise your printer's extrusion consistency, checking whether you are pushing the hotend to its limits. To do so, enable logging `sync_feedback_debug_log: 1` in the mmu_parameters.cfg file and restart. Run a print and after it is complete, execute the below command in the printer shell `~/Happy-Hare/utils/plot_sync_feedback.sh ~/printer_data/logs/sync_5.jsonl` where sync_N being the lane number in use.

You can read more on how to interpret the sync feedback telemetry data in the [Happy Hare wiki](https://github.com/moggieuk/Happy-Hare/wiki/Synchronized-Gear-Extruder#interpreting-telemetry).

**Normal telemetry data with an "unstressed" hotend** </br>
Notice how the orange line is **pretty flat and consistent**. This indicates that there is very little dynamic variation during printing between the EMU and the extruder, meaning the extruder can maintain ideal flow easily throughout the print. Also how the blue line (EMU rotation distance) converges and stabilises fairly quickly to a perfectly stable value.</br></br>


**Telemetry data showing a tangle developing towards the end of the print** </br>
Notice how the orange and blue lines slowly creep away from neutral and then flowguard (red vertical line) triggers saving the print.</br></br>
T2 sim_plot

**Telemetry data showing a hotend that is struggling to keep up with flow when printing at higher flow rates** </br>
Notice how the blue line (RD) and orange line (sensor position) rapidly deviate from neutral when an object with high flow rate is printed.</br></br>


---

← [Step 3: EMU Board Setup](/docs/software_setup/01-board-setup.md) | [Step 5: Calibration and Startup (v3) →](/docs/software_setup/legacy_hhv3/03-calibration-and-startup.md)

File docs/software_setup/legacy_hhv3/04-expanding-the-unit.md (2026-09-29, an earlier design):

# EMU Happy Hare Hardware and Software Setup (Happy Hare v3 – legacy)

> [!WARNING]
> **Legacy guide for Happy Hare v3.** This page is kept for existing Happy Hare v3 installs only. For Happy Hare v4, use the current [Expanding the Unit](/docs/software_setup/04-expanding-the-unit.md) page. See the [legacy v3 guide index](/docs/software_setup/legacy_hhv3) for the rest of the v3 guides.

This section covers adding lanes to an existing EMU installation. It is meant to be read in conjunction with the [Happy Hare wiki](https://github.com/moggieuk/Happy-Hare/wiki).

## Table of Contents

- [Expanding the unit with more lanes](#expanding-the-unit-with-more-lanes)

## Expanding the unit with more lanes

Beyond the electrical connections, the below steps need to be undertaken when adding additional lanes to the EMU unit.

**mmu.cfg**

Add an additional MCU block for each new lane:

```ini
[mcu mmuN]
canbus_uuid: UUID
canbus_interface: can0
```

Add the additional mmu board to the board pins section:

```ini
[board_pins mmu]
mcu: mmu0, mmu1, mmu2, mmu3, mmu4, mmu5, mmu6, mmuN
aliases:
    MMU_GEAR_UART=PA15,
    MMU_GEAR_STEP=PD0,
    MMU_GEAR_DIR=PD1,
    MMU_GEAR_ENABLE=PD2,
    MMU_GEAR_DIAG=,
    MMU_NEOPIXEL=PD3,
    MMU_NEOPIXEL_LOGO=,
    MMU_PRE_GATE=PB7,
    MMU_POST_GEAR=PB5,
    MMU_TENSION=PB8,
    MMU_COMPRESSION=PB9,
    MMU_TH=PA3,
    MMU_FAN=PA0,
    EJECT_BUTTON=PB6,
```

**mmu_hardware.cfg:**

Update the below to reflect your current lane count:

```ini
[mmu_machine]
num_gates: 8
```

Add the additional environment sensors block.

```ini
environment_sensors:   temperature_sensor Lane_0,
      temperature_sensor Lane_1,
                        temperature_sensor Lane_2,
                        temperature_sensor Lane_3,
                        ...
                        temperature_sensor Lane_N
```

Add additional stepper definitions, where N is the lane number:

```ini
...
[tmc2209 stepper_mmu_gear_N]
uart_pin: mmuN:MMU_GEAR_UART_N

[stepper_mmu_gear_N]
step_pin: mmuN:MMU_GEAR_STEP_N
dir_pin: mmuN:MMU_GEAR_DIR_N
enable_pin: !mmuN:MMU_GEAR_ENABLE_N
...
```

Define the additional pre-gate and post gear sensors (pre-stepper, post-stepper)

```ini
[mmu_sensors]
...
pre_gate_switch_pin_N: ^mmuN:MMU_PRE_GATE
post_gear_switch_pin_N: ^mmuN:MMU_POST_GEAR
...
```

Add another neopixel LED's block

```ini
[neopixel mmuN_leds]
pin: mmuN:MMU_NEOPIXEL
chain_count: 2
color_order: GRBW
```

Update the mmu_led's entry and exit LED numbers

```ini
[mmu_leds unit0]
exit_leds:
  neopixel:mmu0_leds (1) # add/remove to match number of lanes
  neopixel:mmu1_leds (1)
  neopixel:mmu2_leds (1)
  neopixel:mmu3_leds (1)
  neopixel:mmu4_leds (1)
  neopixel:mmu5_leds (1)
  neopixel:mmu6_leds (1)
  ...
  neopixel:mmuN_leds (1)
entry_leds:
  neopixel:mmu0_leds (2) # add/remove to match number of lanes
  neopixel:mmu1_leds (2)
  neopixel:mmu2_leds (2)
  neopixel:mmu3_leds (2)
  neopixel:mmu4_leds (2)
  neopixel:mmu5_leds (2)
  neopixel:mmu6_leds (2)
  ...
  neopixel:mmuN_leds (2)
frame_rate: 24
```

**mmu_eject_buttons_hw.cfg**

Define the additional eject buttons in the mmu_eject_buttons_hw.cfg file:

```ini
[gcode_button mmu_eject_button_N]
pin: ^!mmuN:EJECT_BUTTON
press_gcode: _MMU_EJECT_BUTTON GATE=N
```

**mmu_macro_vars.cfg:**

Add an additional tool change gcode macro at the end of the file for each new lane:

```ini
[gcode_macro TN]
gcode: MMU_CHANGE_TOOL TOOL=N
```

**emu_macros.cfg**

Add additional temperature sensor, fan and BME sensor definitions and update the custom fan control macro to use them

Finally dont forget to execute the 2 calibrations for the new lanes - MMU_CALIBRATE_BOWDEN and MMU_CALIBRATE_GEAR as described in the calibration section.

```ini
[temperature_sensor Lane_N]
sensor_type: BME280
i2c_address: 118
i2c_mcu: mmuN
i2c_software_scl_pin: mmuN:PB3
i2c_software_sda_pin: mmuN:PB4

[temperature_sensor _Lane_N_onboard]
sensor_type: temperature_mcu
sensor_mcu: mmuN
min_temp: 0
max_temp: 130

[fan_generic _emu_fan_N]
pin: mmuN:MMU_FAN
max_power: 1
kick_start_time: 0.5

[gcode_macro MMU_FAN_CFG]
...
variable_sensors: ".....,_Lane_N_onboard"
variable_fans:    "......,_emu_fan_N"
...
```

---

← [Legacy v3 guide index](/docs/software_setup/legacy_hhv3) | [Documentation Hub](/docs)

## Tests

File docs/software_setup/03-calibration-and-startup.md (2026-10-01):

# Calibration and Startup

This section covers the first start up checks and calibrating the EMU with Happy Hare v4. It's meant to be read alongside the Happy Hare [Calibration](https://moggieuk.github.io/Happy-Hare-Doc/Calibration/) documentation. If you use AFC instead of Happy Hare, follow the [AFC calibration guide](https://www.afcproject.dev/installation/calibration.html).

> [!NOTE]
> **Running Happy Hare v3?** Use the [legacy v3 Calibration and Startup guide](/docs/software_setup/legacy_hhv3/03-calibration-and-startup.md). The v3 parameter names and the `proportional` extruder homing option don't exist in v4.

## Table of Contents

- [First start up](#first-start-up)
- [Calibrating the unit](#calibrating-the-unit)
  - [Check the calibration settings](#check-the-calibration-settings)
  - [Calibrate the EMU Sync PSF sensor (PSF only)](#calibrate-the-emu-sync-psf-sensor-psf-only)
  - [Bowden length auto-calibration](#bowden-length-auto-calibration)
  - [Toolhead dimensions](#toolhead-dimensions)
- [Manual unit calibration (optional - if not satisfied with automated calibrations)](#manual-unit-calibration-optional---if-not-satisfied-with-automated-calibrations)
  - [Lane rotation distance calibration](#lane-rotation-distance-calibration)
  - [Bowden tube calibration](#bowden-tube-calibration)

## First start up
Follow the first start up procedure below to check that the EMU is wired and working correctly. Use `MMU_SENSORS` at any point to see the live state of every sensor.

1. **Lane sensors.** Insert filament into each lane. The lane grabs it and parks it just before the post-stepper sensor. Run `MMU_SENSORS` and check that, for that lane, the pre-gate (entry) sensor `mmu_entry_N` shows **TRIGGERED** and the post-stepper (exit) sensor `mmu_exit_N` shows **Open**. If they're the other way round, the two sensors are wired backwards. Swap that lane's pins in `menuconfig` under **Pins / TMC → Mmu entry sensor pins** and **Mmu exit sensor pins**.
2. **Lane stepper.** Run the commands below, replacing `0` with the lane number. The filament should move forward (away from the spool), and `mmu_exit_N` should now show **TRIGGERED**. If the filament moves backwards, invert that lane's **Gear dir pin** by adding a `!` in front of it (**Pins / TMC → Gear pins**). If the sensor doesn't trigger, you may have a wire break.
   ```
   MMU_SELECT GATE=0
   MMU_TEST_MOVE MOVE=50
   ```
3. **Eject button.** Press the lane's eject button. The filament should be ejected from the lane. If not, you may have a wire break.
4. **LEDs.** Check that the LEDs change as filament is inserted. The eject button LEDs show the gate status, and the LED inside the dry box shows the filament colour (white if you're not using Spoolman). If they don't light, check the power to the LEDs and the in/out order of the LED chain. Run `MMU_LED` to see which effect is set for each LED group.
5. **EMU Sync.**
   - **Dual switches:** Push the two sides of the EMU Sync together. `filament_tension` should show **TRIGGERED**. Pull them apart until the other switch clicks. `filament_compression` should show **TRIGGERED**. If these are the wrong way round, swap the tension and compression pins in `menuconfig` under **Pins / TMC → Sync-feedback Buffer**.
   - **PSF:** Covered in [Calibrate the EMU Sync PSF sensor](#calibrate-the-emu-sync-psf-sensor-psf-only).
6. **First load.** If you're using the PSF, first do Steps 1 and 2 of [Calibrate the EMU Sync PSF sensor](#calibrate-the-emu-sync-psf-sensor-psf-only). The installer's placeholder PSF values can make the first load fail. Then home the printer, load filament to the first lane and run `T0`. The hotend heats up and the lane loads filament to the nozzle. If this is the lane's first load, its bowden length is auto-calibrated first. If the filament crashes into the extruder entry, your bowden length calibration is off. If too much material comes out of the nozzle, your toolhead dimensions are off.

**After you have set up your filament cutter** (tip cutting, see [toolhead cutter setup](/docs/software_setup/02-software-setup.md#toolhead-cutter)):
1. Run `MMU_UNLOAD`. The toolhead should cut the filament and rewind it back to the EMU.
2. If the toolhead fails to cut, the cutter settings aren't right. See the Happy Hare [tip cutting](https://moggieuk.github.io/Happy-Hare-Doc/Macro-Toolhead-Tip-Cutting/) docs.

## Calibrating the unit

The EMU's sensors let Happy Hare calibrate the unit automatically, so **in most setups you don't need to run any calibration commands by hand**:

- **Bowden length** is measured automatically for each lane the first time that lane is loaded. This uses the [extruder homing method](/docs/software_setup/02-software-setup.md#extruder-homing-method) you chose in Step 4.
- **Lane rotation distance** doesn't need calibrating. During printing, the EMU Sync keeps each lane stepper synchronised with the extruder.
- **The EMU Sync PSF sensor** (if fitted) needs a one-off calibration with `MMU_CALIBRATE_PSENSOR`.
- **Toolhead dimensions** come from the toolhead you picked in `menuconfig`, or from your own measurements.

All of the settings below are changed in `menuconfig`. To open it, run `./install.sh -i` from your `Happy-Hare` folder. Save when you're done, and restart Klipper.

### Check the calibration settings

The EMU defaults are under **Other Settings → Calibration/Autotuning** and should look like this:

| Setting | EMU value | What it does |
|---|---|---|
| Auto calibrate bowden length (`autocal_bowden_length`) | `1` | Calibrates each lane's bowden length on its first load |
| Autotune bowden length (`autotune_bowden_length`) | `0` | Keeps the calibrated bowden length fixed. It isn't adjusted over time |
| Don't force rotation distance calibration (`skip_cal_rotation_distance`) | `1` | Uses the default lane rotation distance. The EMU Sync corrects it while printing |
| Autotune rotation distance (`autotune_rotation_distance`) | `0` | Leave it off |

There's no encoder on the EMU, so encoder calibration doesn't apply.

### Calibrate the EMU Sync PSF sensor (PSF only)

Skip this section if you're using the dual-switch EMU Sync. The switches don't need calibrating.

The installer's default PSF values (`analog_max_compression: 1.0`, `analog_max_tension: 0.0`, `analog_neutral_point: 0.5`) are placeholders. **Replace them before the first load.** Happy Hare uses these values to detect the extruder during bowden calibration, so placeholder values can make the first load fail.

**Step 1: Check the sensor and take rough readings.** With the filament unloaded, run:
```
MMU_SENSORS
```
Look at the `filament_proportional` raw value. The EMU Sync rests in the tension position, so with filament unloaded the raw value should be close to 0.

1. Pull the bowden tubes apart to fully expand the EMU Sync (compression), and run `MMU_SENSORS` again. Note the raw value. It should be above ~0.9.
2. Push the tubes together to fully squeeze the EMU Sync (tension), and run `MMU_SENSORS` again. Note the raw value. It should be below ~0.1.

> [!IMPORTANT]
> If the raw value barely changes as you move the EMU Sync, check your wiring. The PSF signal must go to an analog (thermistor) pin.
>
> **If the sensor reads close to 1.0 with filament unloaded**, the magnet is in the wrong way round. Flip the magnet. If you can't flip it, the calibration values below will come out swapped (the high value becomes `analog_max_tension`).

**Step 2: Enter the rough values.** In `menuconfig`, go to **MMU Features / Additions → Buffer config**. Enter the expanded reading as `analog_max_compression` and the squeezed reading as `analog_max_tension`. For `analog_neutral_point`, enter the average of the two. Save and restart Klipper.

**Step 3: Calibrate the sensor.**

1. Load filament from any lane to the toolhead using a Tx command (T0, T1, etc.). This first load also auto-calibrates that lane's bowden length.
2. Run:
   ```
   MMU_CALIBRATE_PSENSOR
   ```
   If you have a long bowden tube with a lot of slack, give it more travel: `MMU_CALIBRATE_PSENSOR MOVE=40`.
3. Enter the three reported values (`analog_max_compression`, `analog_max_tension` and `analog_neutral_point`) in **MMU Features / Additions → Buffer config**. Save and restart Klipper.

The results should look like this:
```ini
analog_max_compression: 0.9435
analog_max_tension:     0.0982
analog_neutral_point:   0.5275
```

> [!IMPORTANT]
> If the calibrated values differ from your Step 1 readings by more than ~0.1, the calibration was probably thrown off by bowden slack or friction in the sensor. Check that the EMU Sync moves freely, then run the calibration again (with `MOVE=40` for long bowdens).

**Step 4: Re-measure the first lane.** The lane you loaded in Step 3 was calibrated using the rough values, so measure it again. Unload it, keep that gate selected, and run `MMU_CALIBRATE_BOWDEN RESET=1`. Its bowden length will be measured again on its next load.

### Bowden length auto-calibration

With `autocal_bowden_length: 1`, the first time you load a lane it feeds filament until the extruder endstop triggers. It then saves that distance as the lane's bowden length. Each lane has its own bowden length, because each lane has a different path to the combiner.

This needs the [extruder homing method](/docs/software_setup/02-software-setup.md#extruder-homing-method) set in Step 4. Bowden auto-calibration won't work if the method is `none`.

> [!IMPORTANT]
> Auto-calibration can take a few minutes per lane, especially when homing with the PSF. To avoid this happening during your first print, load each lane once beforehand using Tx commands (T0, T1, etc.) until every lane has been calibrated.

**Re-calibrating after maintenance:** Anything that changes a lane's bowden length or effective rotation distance needs its bowden length measured again. For example, replacing a bowden tube, re-routing the combiner or refurbishing a lane. With the filament unloaded (parked in the lane), select the lane and reset its value:
```
MMU_SELECT GATE=2
MMU_CALIBRATE_BOWDEN RESET=1
```
The lane is re-calibrated automatically on its next load. To measure it straight away instead, follow [Bowden tube calibration](#bowden-tube-calibration) below.

If you'd rather not rely on the automatic values, or you don't have the required sensors, the calibrations can also be [run manually as described later on this page](#manual-unit-calibration-optional---if-not-satisfied-with-automated-calibrations).

### Toolhead dimensions

Happy Hare also needs your toolhead's dimensions to load and unload accurately. For EMU users there are three ways to get them:

1. **Your toolhead is in the `menuconfig` Toolhead list.** Selecting it pre-fills community-measured values. This is a good starting point.
2. **Your toolhead has a toolhead sensor.** You can measure the values with `MMU_CALIBRATE_TOOLHEAD`. See the Happy Hare [Toolhead calibration](https://moggieuk.github.io/Happy-Hare-Doc/Calibration-Toolhead/) guide.
3. **Measure the values by hand** using the EMU guides:
   - [Manual Sensorless Toolhead Calibration](/docs/software_setup/07-manual-toolhead-calibration.md)
   - [Manual Toolhead Calibration with Two Sensors](/docs/software_setup/08-manual_toolhead_calibration_two_sensors.md)

   With v4, enter the measured values in `menuconfig` under **Toolhead sensors/settings → Toolhead dimensions** rather than editing `mmu_parameters.cfg` directly. Enter the cutter values (`blade_pos`, `retract_length`) under **Macro Variables → Toolhead tip cutting (`_MMU_CUT_TIP`)** as **Blade position** and **Retract length**. This way they aren't overwritten when you next run the installer.

## Manual unit calibration (optional - if not satisfied with automated calibrations)
Both calibrations below work the same way in Happy Hare v4 as they did in v3. Every calibration command also accepts `SAVE=0` to measure and report a value without saving it, and `RESET=1` to clear the saved value for the selected lane. The results are stored in `mmu_vars.cfg`.

### Lane rotation distance calibration
This calibration is optional on the EMU. The EMU Sync corrects the rotation distance while printing (see [Check the calibration settings](#check-the-calibration-settings)). Calibrating each lane still makes the non-synced bowden moves more accurate.

Before you start, remove all bowden tubes from the rear of the dry boxes that go to the combiner. Add a short length of PTFE tubing (50mm is enough) to the first lane's dry box exit. This guides the filament and stops it grinding on the ECAS connector. Then load some filament and follow the steps below to grip it and feed it.

**Step 1:** Select the gate, load filament and move it 200mm (or more) until filament shows at the lane's exit ECAS connector.
```
MMU_SELECT GATE=0
MMU_TEST_MOVE MOVE=200 # run this once or more until filament comes out of the dry box.
```
**Step 2:** Cut the filament poking out of the short PTFE tube flush with the end of the tube. Then run:
```
MMU_TEST_MOVE MOVE=100
```
Cut the filament flush with the PTFE tube again, and measure the piece you cut off. Use that measurement to calibrate the lane's rotation distance:
```
MMU_CALIBRATE_GEAR MEASURED=102.5 #102.5 is an example value and should correspond to the value measured.
```
**Step 3:** Repeat for all lanes:
```
MMU_SELECT GATE=1 # then 2,3,4, etc etc.
MMU_TEST_MOVE MOVE=200 # run this once or more until filament comes out of the dry box.
..... cut the filament at the box ptfe tube exit .....
MMU_TEST_MOVE MOVE=100
MMU_CALIBRATE_GEAR MEASURED=102.5 #102.5 is an example value and should correspond to the value measured.
```

> [!IMPORTANT]
> If you see a big difference between gates, check that your BMG gears are centred with the filament path and that the tension is as close to equal as possible between them.

Rotation distance calibration is now done! `MMU_CALIBRATE_GEAR RESET=1` puts the selected lane back to the default.

> [!NOTE]
> A lane's bowden length depends on its rotation distance. If you re-calibrate a lane's rotation distance, calibrate its bowden length again too.

### Bowden tube calibration
Now remove the short PTFE tube from the rear of the dry box. Connect the combiner and your bowden tube to the EMU Sync, and from there to the toolhead. The last calibration measures the length of bowden tube from each lane's filament parking position to the toolhead. Each lane has a different length, so each one needs to be calibrated separately using the procedure below. The filament must be unloaded (parked in the lane) before you start.

> [!IMPORTANT]
> While calibrating each lane's bowden length, hold the EMU Sync in the tension position by hand (the two tubes pushed towards each other). This is required for the dual-switch EMU Sync, and recommended for the PSF. The calibration measures how much filament the lane feeds before the extruder endstop triggers. If the EMU Sync is left free, its springs can compress or expand unpredictably and give an incorrect result. Holding it in tension also makes the measured bowden length slightly shorter. This helps stop the filament hitting the extruder if the lane rotation distance is slightly off.

```
MMU_SELECT GATE=0
MMU_CALIBRATE_BOWDEN
```
Repeat this for each lane, for example:
```
MMU_SELECT GATE=1 # then 2,3,4, etc etc.
MMU_CALIBRATE_BOWDEN
```
The unit is now fully calibrated and ready to use!

---

← [Step 4: Software Setup](/docs/software_setup/02-software-setup.md) | [Step 6: Slicer Setup →](/docs/software_setup/05-slicer-setup.md)

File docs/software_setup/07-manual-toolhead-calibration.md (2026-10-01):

# Manual Sensorless Toolhead Calibration for Happy Hare

A manual calibration procedure for the toolhead dimensions used by Happy Hare, intended for setups **without** any toolhead filament sensor. 

These are the parameters you will derive and later enter into `mmu_parameters.cfg`:
- `toolhead_extruder_to_nozzle` — extruder drive gears → internal nozzle shoulder
- `toolhead_entry_to_extruder` — top of the toolhead bowden coupler → extruder drive gears
- `toolhead_residual_filament` — molten material left in the melt zone after a normal unload
- `variable_blade_pos` and `variable_retract_length` — only if you have a toolhead cutter (set in `mmu_macro_vars.cfg`)

`toolhead_sensor_to_nozzle` is not applicable (no sensor) and should be set to the same value as `toolhead_extruder_to_nozzle`

---

## What you need

- A digital calliper or a steel ruler with mm graduations
- A fine, permanent marker (Sharpie ultra-fine) or a sharp scribe
- A couple of short lengths (≈ 300 mm) of fresh, unused filament of the type you normally print with
- Side cutters / flush cutters
- Your printer has the bowden tube disconnectable at the **toolhead entry**

A short reminder before you start: every measurement is a difference between **a reference plane** on the toolhead and **a mark on the filament**. Be religious about always referencing the same physical surface — usually the **top face of the toolhead bowden coupler** (where the bowden tube seats into the push-fit collet). If you reference different surfaces between measurements, your numbers will drift by several mm.

If you have a Belay (or similar tension/compression sensor) on the bowden path, lock or remove it for the whole procedure — its movement will corrupt every measurement.

For context, the diagrams below show the filament geometry the measurements below are characterising — tip cutting on the top, tip forming on the bottom:

<p align="center">
  Unloading with tip cutting
  Unloading with tip forming
</p>

---

## Step 0 — Cold pull the nozzle

Every "clean" measurement assumes the melt zone is completely empty. Perform a cold pull first (heat, purge, cool to ~90 °C for PLA / ~110 °C for PETG, pull firmly). Inspect the pulled tip — it should come out cleanly shaped to the inside of the nozzle. If it tears, repeat.

If you prefer, run `MMU_COLD_PULL MATERIAL=[nylon|pla|abs|petg]` and follow the prompts.

---

## Step 1 — Measure `toolhead_extruder_to_nozzle` (cold, clean nozzle)

This is the distance from the **extruder drive gears** to the **internal nozzle shoulder** (the flat where the melt chamber narrows into the orifice — *not* the nozzle tip).

1. With the printer **cold** and the extruder empty, disengage the extruder idler so filament can move freely past the drive gears (most extruders have a tension lever or thumbscrew for this).
2. Disconnect the bowden tube at the toolhead entry. Leave the coupler in place.
3. Take a fresh piece of filament with a **square, flush-cut tip**. The squareness of this tip matters — recut with side cutters if the end looks bevelled.
4. Feed the filament **down through the toolhead entry**, through the extruder, and into the hotend until you feel a hard, solid stop. That stop is the internal nozzle shoulder. Push firmly but do not bend the filament — if it buckles, your number will be short.
5. Holding the filament still, mark it precisely level with the **top face of the toolhead coupler** (your reference plane).
6. Withdraw the filament without smearing the mark.
7. With callipers, measure from the **tip** of the filament to the **mark**. Call this distance **A**.

You now have:

> measured length from toolhead coupler → nozzle shoulder = **A**

You can't yet separate that into "entry → extruder" and "extruder → nozzle" — Step 2 does that.

Repeat the push-mark-pull twice more with fresh tips and average the three readings. They should agree within ±0.3 mm. If not, recut more carefully and try again.

---

## Step 2 — Measure `toolhead_entry_to_extruder` (cold)

This is the distance from the **top of the toolhead coupler** to the **extruder drive gears**.

1. Re-engage the extruder idler (so the gears grip the filament).
2. Cut a fresh, square tip on a new piece of filament.
3. Feed the filament down through the toolhead entry. Push **gently** until the tip is just caught by the drive gear teeth — you will feel it bite. **Stop immediately**; do not let the extruder pull it in.
4. Holding the filament still, mark it level with the top face of the coupler.
5. Carefully reverse the extruder a few mm (MOVE the gear backwards, or release the idler) and withdraw the filament with the mark intact.
6. Measure tip → mark with callipers. Call this distance **B**.

You now have:

> `toolhead_entry_to_extruder` = **B**

And by subtraction:

> `toolhead_extruder_to_nozzle` = **A − B**

**These are your first two parameter values. Note them down.**

---

## Step 3 — Dirty the nozzle (simulate a real unload)

This step prepares for measuring residual filament. Pick the branch that matches your toolhead.

### If you use tip forming (no cutter)

1. Heat the nozzle to your normal print temperature.
2. `MMU_LOAD` (or `Tx`).
3. Manually extrude ~30 mm of filament from the web UI to fully prime the melt zone.
4. `MMU_UNLOAD`.
5. Turn the heater off and wait until the hotend is cold to the touch.

### If you use tip cutting

1. Heat the nozzle to print temperature.
2. `MMU_LOAD` (or `Tx`).
3. Manually extrude ~30 mm.
4. `MMU_UNLOAD SKIP_TIP=1` — this is important; you want the unload **without** the cutting action, so the residual reflects what tip forming would have left.
5. Turn the heater off and let the hotend cool fully.

---

## Step 4 — Measure `toolhead_residual_filament` (cold, dirty nozzle)

The hotend is now cold and contains the frozen plug of residual filament left after a normal unload.

1. Disengage the extruder idler.
2. Cut a fresh, square tip on a new piece of filament.
3. Feed it down through the toolhead entry into the extruder and on toward the nozzle. You will hit a soft stop — the cold residual plug — *before* you reach the metal nozzle shoulder. Push with the same firmness as before; you should feel the plug compress slightly then resist.
4. Mark the filament level with the top face of the coupler.
5. Withdraw and measure tip → mark. Call this distance **C**.

Then:

> `toolhead_residual_filament` = **A − C**

(Where **A** is the clean measurement from Step 1.)

Sanity check: residual is normally **10-20 mm** for standard hotends, **20-30 mm** for CHT / high-flow setups. If you get a negative number or > 40 mm, something has shifted in your measurement plane — repeat.

Notes:
- It is normal for **C** to differ slightly between filament types (PETG residual is often ≥ PLA). You can recalibrate per filament if you care.
- Re-running this measurement on fresh filament after a fresh cold pull and reload is the only way to verify it.

---

## Step 5 — Cutter parameters (skip if you don't have a toolhead cutter)

You will derive `variable_blade_pos` (distance from extruder gears to the blade) and from it a safe `variable_retract_length`.

### Method A — full procedure (most accurate)

1. `MMU_LOAD` (or `Tx`) to load filament with the nozzle hot.
2. Turn the heater off and wait until cold.
3. Manually press the cut lever to cut the filament inside the toolhead.
4. `MMU_UNLOAD SKIP_TIP=1` — this ejects everything **above** the cut and leaves the short stub from extruder gears → blade still inside the toolhead.
5. Disengage the extruder idler. Cut a fresh, square tip on a new piece of filament.
6. Feed it down through the toolhead entry until it stops against the stub. Mark at the top face of the coupler.
7. Withdraw and measure tip → mark. Call this distance **D**.

Then:

> `variable_blade_pos` = **A - D**

### Setting `variable_retract_length`

A safe starting value is **5 mm shorter than the blade position**:

> `variable_retract_length` = `variable_blade_pos` - `toolhead_residual_filament` − 5

This leaves a 5 mm stub above the cut zone, which is about as aggressive as is safe — shorter stubs reduce purge requirements but risk clogs because you start nibbling at melted filament. If you see clogs after the first few colour changes, increase `variable_retract_length` by 1–2 mm at a time.

---

## Step 6 — Update your config files

Open `mmu_parameters.cfg` and update:

```
toolhead_extruder_to_nozzle: <A − B>
toolhead_entry_to_extruder:  <B>
toolhead_residual_filament:  <A − C>
# toolhead_sensor_to_nozzle stays at its existing value; you have no sensor
```

If you have a cutter, open `mmu_macro_vars.cfg` and update:

```
variable_blade_pos:       <A - D>   # (or A - D + 0.5 with Method B)
variable_retract_length:  <blade_pos − residual − 5>
```

Then `RESTART` (or `FIRMWARE_RESTART` if Klipper requires it).

---

## Step 7 — Sanity check the result

After restarting:

1. Run a real `Tx` change at the start of a small test print. Watch the wipe tower: a clean transition with no blob is the goal.
2. If you see consistent blobbing on the wipe tower, the residual or the extruder-to-nozzle is slightly off — fine tune as the wiki describes via `toolhead_ooze_reduction` (start at 0 and increase by 0.5 mm at a time, positive values shorten the load).

---

## Quick reference

| Step | Filament state | Nozzle temp | Measurement | Yields |
|---|---|---|---|---|
| 1 | Fresh tip, idler off | Cold, clean | tip → mark = **A** | (entry → nozzle shoulder) |
| 2 | Fresh tip, idler on | Cold | tip → mark = **B** | `toolhead_entry_to_extruder` |
| 3 | Load + dirty unload | Hot then cold | — | preparation |
| 4 | Fresh tip, idler off | Cold, dirty | tip → mark = **C** | `toolhead_residual_filament` = A − C |
| 5 | Fresh tip, after cut + SKIP_TIP unload | Cold | tip → mark = **D** | `variable_blade_pos` = D − B |

Derived:

- `toolhead_extruder_to_nozzle` = **A − B**

---

## Common pitfalls

- **Inconsistent reference plane.** Always mark at the same physical surface. The push-fit collet on the coupler often sits a couple of mm above the coupler body — pick one and stick to it.
- **Bevelled filament tips.** A sloppy cut adds 0.5–1 mm of slop to every reading. Cut flush each time.
- **Buckled filament during push.** If filament bends in the bowden or above the extruder, your "stop" is bogus and the number will be short. Use a fresh straight piece, push slowly.
- **Skipping the cold pull.** Hidden residue at the nozzle shoulder will give you a short `toolhead_extruder_to_nozzle` and then a fake-large `toolhead_residual_filament`.
- **Forgetting to subtract B.** Several of the parameters are *from the extruder*, but you're measuring *from the coupler*. The B subtraction is what converts one to the other.

---

← [Step 4: Software Setup](/docs/software_setup/02-software-setup.md) | [Documentation Hub →](/docs)

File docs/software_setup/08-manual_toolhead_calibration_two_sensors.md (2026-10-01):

# Manual Toolhead Calibration with Two Sensors for Happy Hare

A manual calibration procedure for the toolhead dimensions used by Happy Hare, intended for setups with **two toolhead sensors**: a pre-extruder entry sensor (Happy Hare normally names this `extruder`) **and** a post-extruder toolhead sensor (Happy Hare normally names this `toolhead`). Two sensors means you can capture three reference events on a single filament push, and you can also calibrate `toolhead_sensor_to_nozzle` properly.

These are the parameters you will derive and later enter into `mmu_parameters.cfg`:

- `toolhead_extruder_to_nozzle` — extruder drive gears → internal nozzle shoulder
- `toolhead_entry_to_extruder` — entry sensor trigger point → extruder drive gears
- `toolhead_sensor_to_nozzle` — toolhead sensor trigger point → internal nozzle shoulder
- `toolhead_residual_filament` — molten material left in the melt zone after a normal unload
- `variable_blade_pos` and `variable_retract_length` — only if you have a toolhead cutter (set in `mmu_macro_vars.cfg`)

---

## What you need

- A digital calliper or a steel ruler with mm graduations
- A fine, permanent marker (Sharpie ultra-fine) or a sharp scribe — ideally **two colours**, since you will mark the same piece of filament three times in Step 1
- A couple of short lengths (≈ 300 mm) of fresh, unused filament of the type you normally print with
- Side cutters / flush cutters
- Your printer with the bowden tube disconnectable at the **toolhead entry**
- A way to see sensor state in real time. Any of: a Mainsail/Fluidd tab showing the filament sensors, repeated `QUERY_FILAMENT_SENSOR SENSOR=extruder` / `QUERY_FILAMENT_SENSOR SENSOR=toolhead` commands, or simply listening for the sensor microswitch click if your sensors are mechanical

A short reminder before you start: every measurement is a difference between **a reference plane** on the toolhead and **a mark on the filament**. Be religious about always referencing the same physical surface — usually the **top face of the toolhead bowden coupler** (where the bowden tube seats into the push-fit collet). If you reference different surfaces between measurements, your numbers will drift by several mm.

For context, the diagrams below show the filament geometry the measurements below are characterising — tip cutting on the top, tip forming on the bottom:

<p align="center">
  Unloading with tip cutting
  Unloading with tip forming
</p>

---

## Step 0 — Cold pull the nozzle

Every "clean" measurement assumes the melt zone is completely empty. Perform a cold pull first (heat, purge, cool to ~90 °C for PLA / ~110 °C for PETG, pull firmly). Inspect the pulled tip — it should come out cleanly shaped to the inside of the nozzle. If it tears, repeat.

If you prefer, run `MMU_COLD_PULL MATERIAL=[nylon|pla|abs|petg]` and follow the prompts.

---

## Step 1 — Three-event push: measure A1, A2 and A3 (cold, clean nozzle)

This single push captures everything except the extruder-gear position. With the nozzle empty and cold, you push fresh filament from the toolhead entry all the way to the nozzle shoulder. You stop briefly and mark the filament **at the coupler top** three times: once when the entry sensor triggers, once when the toolhead sensor triggers, once when the tip hits the nozzle shoulder.

1. With the printer **cold** and the extruder empty, disengage the extruder idler so filament can move freely past the drive gears.
2. Disconnect the bowden tube at the toolhead entry. Leave the coupler in place.
3. Open Mainsail/Fluidd (or whatever shows your sensor state live). Confirm both `extruder` and `toolhead` sensors currently read **not triggered**.
4. Take a fresh piece of filament with a **square, flush-cut tip** (recut if it looks bevelled).
5. Begin feeding the filament **down through the toolhead entry**. Push slowly and steadily.
6. The moment the **entry sensor** flips to triggered, **stop**. Holding the filament still, mark it precisely level with the **top face of the toolhead coupler**. Use one colour. Call this mark **M1**.
7. Continue pushing slowly. The moment the **toolhead sensor** flips to triggered, **stop**. Mark again at the coupler top — ideally in a different colour, or with a double tick so you can tell it apart from M1. Call this mark **M2**.
8. Continue pushing until you feel a hard, solid stop — the internal nozzle shoulder. Mark a third time at the coupler top. Call this **M3**.
9. Withdraw the filament carefully without smearing the marks.
10. With callipers, measure tip → M1, tip → M2 and tip → M3. Call those distances **A1**, **A2** and **A3** respectively.

You now have three coupler-anchored positions on the filament:

> A1 = coupler → entry sensor trigger
>
> A2 = coupler → toolhead sensor trigger
>
> A3 = coupler → nozzle shoulder

Repeat the whole push-mark-pull at least once more with a fresh tip and average. The three values should be repeatable to ±0.3 mm. If A1 jumps around by more than that, your sensor probably has hysteresis — always push **in one direction only** (no back-and-forth) on the calibration run.

---

## Step 2 — Measure B (cold, idler engaged)

This is the extruder gear position, anchored to the same coupler reference.

1. Re-engage the extruder idler.
2. Cut a fresh, square tip on a new piece of filament.
3. Feed the filament down through the toolhead entry. Push **gently** until the tip is just caught by the drive gear teeth — you will feel it bite. **Stop immediately**; do not let the extruder pull it in.
4. Holding the filament still, mark it level with the top face of the coupler.
5. Carefully reverse the extruder a few mm (or release the idler) and withdraw the filament with the mark intact.
6. Measure tip → mark with callipers. Call this distance **B**.

You can now derive three parameters:

> `toolhead_extruder_to_nozzle` = **A3 − B**
>
> `toolhead_entry_to_extruder` = **B − A1**
>
> `toolhead_sensor_to_nozzle` = **A3 − A2**

Sanity check: A2 − B should be a small positive number (the distance from the extruder gears down to the toolhead sensor — typically 5–20 mm depending on toolhead). And `(A2 − B) + (A3 − A2)` must equal `(A3 − B)` — if it doesn't, you've made an arithmetic slip.

**These are your first three parameter values. Note them down.**

---

## Step 3 — Dirty the nozzle (simulate a real unload)

This step prepares for measuring residual filament. Pick the branch that matches your toolhead.

### If you use tip forming (no cutter)

1. Heat the nozzle to your normal print temperature.
2. `MMU_LOAD` (or `Tx`).
3. Manually extrude ~30 mm of filament from the web UI to fully prime the melt zone.
4. `MMU_UNLOAD`.
5. Turn the heater off and wait until the hotend is cold to the touch.

### If you use tip cutting

1. Heat the nozzle to print temperature.
2. `MMU_LOAD` (or `Tx`).
3. Manually extrude ~30 mm.
4. `MMU_UNLOAD SKIP_TIP=1` — this is important; you want the unload **without** the cutting action, so the residual reflects what tip forming would have left.
5. Turn the heater off and let the hotend cool fully.

---

## Step 4 — Measure `toolhead_residual_filament` (cold, dirty nozzle)

The hotend is now cold and contains the frozen plug of residual filament left after a normal unload.

1. Disengage the extruder idler.
2. Cut a fresh, square tip on a new piece of filament.
3. Feed it down through the toolhead entry into the extruder and on toward the nozzle. You will hit a soft stop — the cold residual plug — *before* you reach the metal nozzle shoulder. Push with the same firmness as in Step 1; you should feel the plug compress slightly then resist.
4. Mark the filament level with the top face of the coupler.
5. Withdraw and measure tip → mark. Call this distance **C**.

Then:

> `toolhead_residual_filament` = **A3 − C**

Sanity check: residual is normally **10-20 mm** for standard hotends, **20-30 mm** for CHT / high-flow setups. If you get a negative number or > 40 mm, something has shifted in your measurement plane. Repeat the measurement.

Notes:
- Re-running this measurement on fresh filament after a fresh cold pull and reload is the only way to verify it.

---

## Step 5 — Cutter parameters (skip if you don't have a toolhead cutter)

You will derive `variable_blade_pos` (distance from extruder gears to the blade) and from it a safe `variable_retract_length`.

### Method A — full procedure (most accurate)

1. `MMU_LOAD` (or `Tx`) to load filament with the nozzle hot.
2. Turn the heater off and wait until cold.
3. Manually press the cut lever to cut the filament inside the toolhead.
4. `MMU_UNLOAD SKIP_TIP=1` — this ejects everything **above** the cut and leaves the short stub from extruder gears → blade still inside the toolhead.
5. Disengage the extruder idler. Cut a fresh, square tip on a new piece of filament.
6. Feed it down through the toolhead entry until it stops against the stub. Mark at the top face of the coupler.
7. Withdraw and measure tip → mark. Call this distance **D**.

Then:

> `variable_blade_pos` = **A3 - D**

### Setting `variable_retract_length`

A safe starting value is **5 mm shorter than the blade position, with residual subtracted**:

> `variable_retract_length` = `variable_blade_pos` − `toolhead_residual_filament` − 5

This leaves a 5 mm stub above the cut zone, which is about as aggressive as is safe — shorter stubs reduce purge requirements but risk clogs because you start nibbling at melted filament. If you see clogs after the first few colour changes, increase `variable_retract_length` by 1–2 mm at a time.

---

## Step 6 — Update your config files

Open `mmu_parameters.cfg` and update:

```
toolhead_extruder_to_nozzle: <A3 − B>
toolhead_entry_to_extruder:  <B − A1>
toolhead_sensor_to_nozzle:   <A3 − A2>
toolhead_residual_filament:  <A3 − C>
```

If you have a cutter, open `mmu_macro_vars.cfg` and update:

```
variable_blade_pos:       <A3 - D>
variable_retract_length:  <blade_pos − residual − 5>
```

Then `RESTART` (or `FIRMWARE_RESTART` if Klipper requires it).

---

## Step 7 — Sanity check the result

After restarting, you have an extra trick available because of your sensors:

1. Run `MMU_TEST_LOAD` (or perform a `Tx` change) and watch the console. With correctly set `toolhead_entry_to_extruder` and `toolhead_sensor_to_nozzle`, Happy Hare should report the entry and toolhead sensors triggering at exactly the expected filament positions. Discrepancies > 1 mm point at one of A1/A2/A3 being off.
2. Run a real `Tx` change at the start of a small test print. Watch the wipe tower: a clean transition with no blob is the goal.
3. If you see consistent blobbing on the wipe tower, the residual or the extruder-to-nozzle is slightly off — fine tune as the wiki describes via `toolhead_ooze_reduction` (start at 0 and increase by 0.5 mm at a time, positive values shorten the load).

---

## Quick reference

| Step | Filament state | Nozzle temp | Event | Measurement |
|---|---|---|---|---|
| 1a | Fresh tip, idler off | Cold, clean | Entry sensor triggers | tip → M1 = **A1** |
| 1b | Same push | Cold, clean | Toolhead sensor triggers | tip → M2 = **A2** |
| 1c | Same push | Cold, clean | Nozzle shoulder hit | tip → M3 = **A3** |
| 2 | Fresh tip, idler on | Cold | Gears bite | tip → mark = **B** |
| 3 | Load + dirty unload | Hot then cold | — | preparation |
| 4 | Fresh tip, idler off | Cold, dirty | Residual plug stops tip | tip → mark = **C** |
| 5 | Fresh tip, after cut + SKIP_TIP unload | Cold | Stub stops tip | tip → mark = **D** |

Derived:

- `toolhead_extruder_to_nozzle` = **A3 − B**
- `toolhead_entry_to_extruder` = **B − A1**
- `toolhead_sensor_to_nozzle` = **A3 − A2**
- `toolhead_residual_filament` = **A3 − C**
- `variable_blade_pos` = **D − B**
- `variable_retract_length` = `variable_blade_pos` − `toolhead_residual_filament` − 5

---

## Common pitfalls

- **Inconsistent reference plane.** Always mark at the same physical surface. The push-fit collet on the coupler often sits a couple of mm above the coupler body — pick one and stick to it.
- **Bevelled filament tips.** A sloppy cut adds 0.5–1 mm of slop to every reading. Cut flush each time.
- **Sensor hysteresis.** Optical and hall sensors trigger at slightly different positions on the way in vs the way out. Always push in one direction during the calibration push. If you back up to "re-check", start over with a fresh tip.
- **Marking too slowly.** If you stop pushing and *then* the sensor catches up to its trigger position, your mark will be late. Practice the push once before marking — when you see the sensor flip, mark immediately and stop simultaneously.
- **Buckled filament during push.** If filament bends in the bowden or above the extruder, your "stop" is bogus and the number will be short. Use a fresh straight piece, push slowly.
- **Skipping the cold pull.** Hidden residue at the nozzle shoulder will give you a short `toolhead_extruder_to_nozzle` and then a fake-large `toolhead_residual_filament`.
- **Forgetting to subtract B.** Several of the parameters are *from the extruder*, but you're measuring *from the coupler*. The B subtraction is what converts one to the other.

---

← [Step 4: Software Setup](/docs/software_setup/02-software-setup.md) | [Documentation Hub →](/docs)

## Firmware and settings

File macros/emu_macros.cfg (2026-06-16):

# === EMU Lane Temperature and Humidity Sensors ===

# AHT20 Sensor definitions below. Uncomment to enable either the BME or AHT sensor definitions depending
# on your hardware setup.
[temperature_sensor Lane_0]
sensor_type: AHT2X
aht10_report_time: 20
i2c_address: 56
i2c_mcu: mmu0
# SW I2C
i2c_software_scl_pin: mmu0:PB3  # SLB: PB10
i2c_software_sda_pin: mmu0:PB4  # SLB: PB11
# HW I2C
# i2c_bus: i2c3_PB3_PB4 # EBB
# i2c_bus: i2c2_PB10_PB11 # SLB

[temperature_sensor Lane_1]
sensor_type: AHT2X
aht10_report_time: 20
i2c_address: 56
i2c_mcu: mmu1
# SW I2C
i2c_software_scl_pin: mmu1:PB3  # SLB: PB10
i2c_software_sda_pin: mmu1:PB4  # SLB: PB11
# HW I2C
# i2c_bus: i2c3_PB3_PB4 # EBB
# i2c_bus: i2c2_PB10_PB11 # SLB

[temperature_sensor Lane_2]
sensor_type: AHT2X
aht10_report_time: 20
i2c_address: 56
i2c_mcu: mmu2
# SW I2C
i2c_software_scl_pin: mmu2:PB3  # SLB: PB10
i2c_software_sda_pin: mmu2:PB4  # SLB: PB11
# HW I2C
# i2c_bus: i2c3_PB3_PB4 # EBB
# i2c_bus: i2c2_PB10_PB11 # SLB

[temperature_sensor Lane_3]
sensor_type: AHT2X
aht10_report_time: 20
i2c_address: 56
i2c_mcu: mmu3
# SW I2C
i2c_software_scl_pin: mmu3:PB3  # SLB: PB10
i2c_software_sda_pin: mmu3:PB4  # SLB: PB11
# HW I2C
# i2c_bus: i2c3_PB3_PB4 # EBB
# i2c_bus: i2c2_PB10_PB11 # SLB

[temperature_sensor Lane_4]
sensor_type: AHT2X
aht10_report_time: 20
i2c_address: 56
i2c_mcu: mmu4
# SW I2C
i2c_software_scl_pin: mmu4:PB3  # SLB: PB10
i2c_software_sda_pin: mmu4:PB4  # SLB: PB11
# HW I2C
# i2c_bus: i2c3_PB3_PB4 # EBB
# i2c_bus: i2c2_PB10_PB11 # SLB

[temperature_sensor Lane_5]
sensor_type: AHT2X
aht10_report_time: 20
i2c_address: 56
i2c_mcu: mmu5
# SW I2C
i2c_software_scl_pin: mmu5:PB3  # SLB: PB10
i2c_software_sda_pin: mmu5:PB4  # SLB: PB11
# HW I2C
# i2c_bus: i2c3_PB3_PB4 # EBB
# i2c_bus: i2c2_PB10_PB11 # SLB

[temperature_sensor Lane_6]
sensor_type: AHT2X
aht10_report_time: 20
i2c_address: 56
i2c_mcu: mmu6
# SW I2C
i2c_software_scl_pin: mmu6:PB3  # SLB: PB10
i2c_software_sda_pin: mmu6:PB4  # SLB: PB11
# HW I2C
# i2c_bus: i2c3_PB3_PB4 # EBB
# i2c_bus: i2c2_PB10_PB11 # SLB

[temperature_sensor Lane_7]
sensor_type: AHT2X
aht10_report_time: 20
i2c_address: 56
i2c_mcu: mmu7
# SW I2C
i2c_software_scl_pin: mmu7:PB3  # SLB: PB10
i2c_software_sda_pin: mmu7:PB4  # SLB: PB11
# HW I2C
# i2c_bus: i2c3_PB3_PB4 # EBB
# i2c_bus: i2c2_PB10_PB11 # SLB

# BME280 Sensor definitions below 
#[temperature_sensor Lane_0]
#sensor_type: BME280
#i2c_address: 118
#i2c_mcu: mmu0
# SW I2C
#i2c_software_scl_pin: mmu0:PB3  # SLB: PB10
#i2c_software_sda_pin: mmu0:PB4  # SLB: PB11
# HW I2C
# i2c_bus: i2c3_PB3_PB4 # EBB
# i2c_bus: i2c2_PB10_PB11 # SLB

#[temperature_sensor Lane_1]
#sensor_type: BME280
#i2c_address: 118
#i2c_mcu: mmu1
# SW I2C
#i2c_software_scl_pin: mmu1:PB3  # SLB: PB10
#i2c_software_sda_pin: mmu1:PB4  # SLB: PB11
# HW I2C
# i2c_bus: i2c3_PB3_PB4 # EBB
# i2c_bus: i2c2_PB10_PB11 # SLB

#[temperature_sensor Lane_2]
#sensor_type: BME280
#i2c_address: 118
#i2c_mcu: mmu2
# SW I2C
#i2c_software_scl_pin: mmu2:PB3  # SLB: PB10
#i2c_software_sda_pin: mmu2:PB4  # SLB: PB11
# HW I2C
# i2c_bus: i2c3_PB3_PB4 # EBB
# i2c_bus: i2c2_PB10_PB11 # SLB

#[temperature_sensor Lane_3]
#sensor_type: BME280
#i2c_address: 118
#i2c_mcu: mmu3
# SW I2C
#i2c_software_scl_pin: mmu3:PB3  # SLB: PB10
#i2c_software_sda_pin: mmu3:PB4  # SLB: PB11
# HW I2C
# i2c_bus: i2c3_PB3_PB4 # EBB
# i2c_bus: i2c2_PB10_PB11 # SLB

#[temperature_sensor Lane_4]
#sensor_type: BME280
#i2c_address: 118
#i2c_mcu: mmu4
# SW I2C
#i2c_software_scl_pin: mmu4:PB3
#i2c_software_sda_pin: mmu4:PB4 # SLB: PB11
# HW I2C
# i2c_bus: i2c3_PB3_PB4 # EBB
# i2c_bus: i2c2_PB10_PB11 # SLB

#[temperature_sensor Lane_5]
#sensor_type: BME280
#i2c_address: 118
#i2c_mcu: mmu5
# SW I2C
#i2c_software_scl_pin: mmu5:PB3  # SLB: PB10
#i2c_software_sda_pin: mmu5:PB4  # SLB: PB11
# HW I2C
# i2c_bus: i2c3_PB3_PB4 # EBB
# i2c_bus: i2c2_PB10_PB11 # SLB

#[temperature_sensor Lane_6]
#sensor_type: BME280
#i2c_address: 118
#i2c_mcu: mmu6
# SW I2C
#i2c_software_scl_pin: mmu6:PB3  # SLB: PB10
#i2c_software_sda_pin: mmu6:PB4  # SLB: PB11
# HW I2C
# i2c_bus: i2c3_PB3_PB4 # EBB
# i2c_bus: i2c2_PB10_PB11 # SLB

#[temperature_sensor Lane_7]
#sensor_type: BME280
#i2c_address: 118
#i2c_mcu: mmu7
# SW I2C
#i2c_software_scl_pin: mmu7:PB3  # SLB: PB10
#i2c_software_sda_pin: mmu7:PB4  # SLB: PB11
# HW I2C
# i2c_bus: i2c3_PB3_PB4 # EBB
# i2c_bus: i2c2_PB10_PB11 # SLB

# === MMU Fan Auto-Control Configuration ===

# === Temperature sensors ===
[temperature_sensor _Lane_0_onboard]
sensor_type: temperature_mcu
sensor_mcu: mmu0
min_temp: 0
max_temp: 130

[temperature_sensor _Lane_1_onboard]
sensor_type: temperature_mcu
sensor_mcu: mmu1
min_temp: 0
max_temp: 130

[temperature_sensor _Lane_2_onboard]
sensor_type: temperature_mcu
sensor_mcu: mmu2
min_temp: 0
max_temp: 130

[temperature_sensor _Lane_3_onboard]
sensor_type: temperature_mcu
sensor_mcu: mmu3
min_temp: 0
max_temp: 130

[temperature_sensor _Lane_4_onboard]
sensor_type: temperature_mcu
sensor_mcu: mmu4
min_temp: 0
max_temp: 130

[temperature_sensor _Lane_5_onboard]
sensor_type: temperature_mcu
sensor_mcu: mmu5
min_temp: 0
max_temp: 130

[temperature_sensor _Lane_6_onboard]
sensor_type: temperature_mcu
sensor_mcu: mmu6
min_temp: 0
max_temp: 130

[temperature_sensor _Lane_7_onboard]
sensor_type: temperature_mcu
sensor_mcu: mmu7
min_temp: 0
max_temp: 130

# === Fans ===

[fan_generic _emu_fan_0]
pin: mmu0:MMU_FAN
max_power: 1
kick_start_time: 0.5

[fan_generic _emu_fan_1]
pin: mmu1:MMU_FAN
max_power: 1
kick_start_time: 0.5

[fan_generic _emu_fan_2]
pin: mmu2:MMU_FAN
max_power: 1
kick_start_time: 0.5

[fan_generic _emu_fan_3]
pin: mmu3:MMU_FAN
max_power: 1
kick_start_time: 0.5

[fan_generic _emu_fan_4]
pin: mmu4:MMU_FAN
max_power: 1
kick_start_time: 0.5

[fan_generic _emu_fan_5]
pin: mmu5:MMU_FAN
max_power: 1
kick_start_time: 0.5

[fan_generic _emu_fan_6]
pin: mmu6:MMU_FAN
max_power: 1
kick_start_time: 0.5

[fan_generic _emu_fan_7]
pin: mmu7:MMU_FAN
max_power: 1
kick_start_time: 0.5


# === MMU Fan Auto-Control (multi-sensor / multi-fan) ===
#
# Pairs each temperature sensor with a fan by index and controls
# that fan with hysteresis based on the paired sensor.
#
# Example:
#   variable_sensors: "Lane_0_onboard,Lane_0_onboard"
#   variable_fans:    "mmu_fan_0,mmu_fan_1"
#
# Notes:
# - Lists must be comma-separated names (no spaces, or strip spaces).
# - If list lengths differ, the shorter length is used (index pairing).
# - FORCE (below) is global: affects all listed fans.

[gcode_macro MMU_FAN_CFG]
description: Holds configuration/state for multi fan controller.
variable_on_temp: 39.0
variable_off_temp: 37.0
variable_poll_s: 5.0
variable_enabled: True
variable_forced: -1                 # -1=AUTO, 0=all OFF, 1=all ON (global)
variable_sensors: "_Lane_0_onboard,_Lane_1_onboard,_Lane_2_onboard,_Lane_3_onboard,_Lane_4_onboard,_Lane_5_onboard,_Lane_6_onboard,_Lane_7_onboard"   # Comma-separated temperature_sensor names
variable_fans:    "_emu_fan_0,_emu_fan_1,_emu_fan_2,_emu_fan_3,_emu_fan_4,_emu_fan_5,_emu_fan_6,_emu_fan_7"  # Comma-separated fan_generic names
variable_warned_len_mismatch: False # internal: warn once per enable
gcode:

[gcode_macro MMU_FAN_MONITOR_ENABLE]
description: Enable automatic multi-fan control.
gcode:
  SET_GCODE_VARIABLE MACRO=MMU_FAN_CFG VARIABLE=enabled VALUE=True
  UPDATE_DELAYED_GCODE ID=_MMU_FAN_LOOP DURATION=0.1
  RESPOND TYPE=echo MSG="MMU multi-fan monitor ENABLED"

[gcode_macro MMU_FAN_MONITOR_DISABLE]
description: Disable automatic control and switch all fans OFF.
gcode:
  SET_GCODE_VARIABLE MACRO=MMU_FAN_CFG VARIABLE=enabled VALUE=False
  UPDATE_DELAYED_GCODE ID=_MMU_FAN_LOOP DURATION=0
  {% set cfg = printer["gcode_macro MMU_FAN_CFG"] %}
  {% set fans = (cfg.fans|string).replace(' ','').split(',') %}
  {% for f in fans %}
    {% if f|length > 0 %}
      SET_FAN_SPEED FAN={f} SPEED=0.0
    {% endif %}
  {% endfor %}
  RESPOND TYPE=echo MSG="MMU multi-fan monitor DISABLED and all fans OFF"
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

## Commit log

2026-03-29 Add pull down resistor to eject buttons definition to prevent floating pin, materialising as phantom eject triggered on reboot.
2026-04-01 Pull up instead of pull down resistors in the eject button definition
2026-04-02 Add cut indicator to PTFE length tool
    [PTFE Cutter and Length Tool.stl, PTFE Cutter and Length Tool[PSF].stl]
2026-04-04 Added EMU Kit information in the BOM
2026-04-06 Updated hardware config to slightly reduce hold current
2026-04-06 Indicate that PSF sensor calibration needs to be performed after the main calibration sequence is completed
2026-04-06 Update unit calibration guide with full auto calibration details.
2026-04-08 wider trigger part for EMUSync
    [[a]_ECAS_trigger.stl]
2026-04-09 Introduction of the EMU Solo Lane Board
2026-04-10 Move polyhole chassis parts to STLs. Box base without BME holder.
    [Chassis_L_688_Bearing.stl, Chassis_L_688_Bearing[polyhole].stl, Chassis_R_688_Bearing.stl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]
2026-04-10 add inverse pin in PCB LED board
2026-04-13 Updated sync gear current
2026-04-17 Updated LED effects for selected gate with static instead of breathing lights to reduce MCU load
    [emu_macros.cfg]
2026-04-17 SLB configuration
    [emu_macros.cfg]
2026-04-18 Update SLB eject button pin
2026-04-19 Update eject button to the right most JST on the board
2026-04-19 Refined calibration page and software setup workflow
    Refined calibration page and software setup workflow
2026-04-21 Update mmu_gear stepper parameters to reduce MCU load. Doc update on PSF sensor values for consistency (sync current)
2026-04-21 SLB wiring sizes
2026-04-21 Usermods from Dragi2k
    [EMU Lite - Open Nema Option.stl, EMU Lite - Standard Option.stl, EMU_convertible_45front.stl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]
2026-04-21 Updated Dragi2k usermods
    [EMU Lite - Open Nema Option-v1.1.stl, EMU Lite - Open Nema Option.stl, EMU Lite - Standard Option-v1.1.stl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]
2026-04-23 IO Board link in sourcing
2026-04-24 add tpu feet usermod (#51)
    [hexagon_foot.step, hexagon_foot.stl]
2026-04-28 upload TL/BLV wago alternative holder
    [[a]_PTC212-413_Holder (Wago221 alternative).step]
2026-04-28 Add Emu split base (#52)
    [EMU Split base.step, EMU_Split_base_Left_Front.stl, EMU_Split_base_Left_Rear.stl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]
2026-04-29 EMU_Split_base fix small typos & renaming (#53)
    - Rename middle lane to expander to match original naming
    [EMU_Split_base_Expander_Front.stl, EMU_Split_base_Expander_Rear.stl]
2026-05-06 Add wire order warning to Trianglelab kit in sourcing.md
2026-05-10 Updated EMUSync PSF manual with tension/compression direction
2026-05-14 Created macro to bulk calibrate bowden tube lengths (MMU_CALIBRATE_BOWDENS)
    [emu_macros.cfg]
2026-05-14 Updated calibration and start up to reference mmu calibrate bowdens convenience macro
2026-05-19 Manual toolhead calibration instructions
2026-05-19 Updated guides with manual extruder calibration instructions for sensorless toolheads.
2026-05-19 Added toolhead calibration guide for two sensor toolhead
2026-05-20 LED PCB button manual
2026-05-20 EMU LED PCB Manual linking
2026-05-26 CAD file update
    [Filamentalist_polyhole_frame.step, [a]_Rim_Roller_SquareNut_x2.step]
2026-05-29 Update EMU Macros with HW I2C definitions in addition to SW I2C definitions
    [emu_macros.cfg]
2026-05-29 Updated emu macros doc with HW/SW I2C bus notes
2026-06-04 Errata in toolhead calibration guide
2026-07-20 Fix for issue #72 - stale RH read prior to first poll timer expiration (#78)
    * Update Readme.md
    * fixing issue #72, where BME280 sensor stays at 97% RH until the end of the first timer delay
    * fixed typo in comment line 164
2026-08-06 Add EMU_I2C_MUX_Board user mod
    [EMU_I2C_MUX_Board_3D_PCB1_2026-08-06.step, EMU_I2C_MUX_Board_BOM_Board1_PCB1_2026-08-06.xlsx, EMU_I2C_MUX_Board_PickAndPlace_PCB1_2026_08_06.csv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]
2026-08-12 Updated part print guidelines
2026-08-12 Beta (pre-release) filamentalist assembly manual upload
2026-08-12 Minor updates to filamentalist manual
2026-08-13 Updated imaging on Filamentalist Assembly Manual
2026-08-13 Partial styling update to the EMU LED Button PCB manual
2026-08-13 Styling updates to EMUSync housing manual
2026-08-13 Update eject button pin for SLB to match Git Repo
2026-08-14 Update eject button inversion in docs (#83)
2026-08-14 Update base wiring diagrams following #83 (#84)
    - Update Eject switch wiring : use NO instead of NC pin
2026-08-17 Updated EMU LED Button PCB manual (styling and consistency improvements)
2026-09-16 EMU_Split_base was printed and tested by DeWarePeb
2026-09-25 Add base extender with rear wire opening
    [Multi_Lane_Base-Expander_with_rear_wire_opening.step]
2026-10-05 Fixed missing m3x8 SHCS screw designation on the neopixel holder
2026-10-08 frst push
    [250mm_adjusted_Latch.stl, 250mm_adjusted_Lid.stl]
2026-10-10 docs: update hatch screw warning image
2026-10-22 Add LED holder for NFC
2026-10-27 Update slicer setup for HHV4 change filament g-code.

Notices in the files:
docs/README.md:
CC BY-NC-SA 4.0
